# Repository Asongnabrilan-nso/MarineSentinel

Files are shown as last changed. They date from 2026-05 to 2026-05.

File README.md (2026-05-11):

# 🌊 MarineSentinel

MarineSentinel Floating on Ocean

AI-powered marine debris detection and water quality monitoring device. MarineSentinel floats on water bodies (oceans, seas, rivers) and continuously:

- **Detects plastic debris** (plastic bags, plastic bottles) via an Edge Impulse image-classification model running on the MPU.
- **Monitors water quality** (pH, turbidity, water temperature, TDS) via the MCU's sensor interface.
- **Streams all data** to a local in-device WebUI (real-time) and a remote Firebase dashboard (global access).
- **Shows live camera feed** in the local WebUI and uploads periodic snapshots to the remote Firebase dashboard.

---

## Table of Contents

1. [System Architecture](#system-architecture)
2. [Hardware Requirements](#hardware-requirements)
3. [Wiring Diagram](#wiring-diagram)
4. [Software Setup](#software-setup)
   - [A — UNO Q MCU Sketch (App Lab)](#a--uno-q-mcu-sketch-app-lab)
   - [B — UNO Q MPU Python App (App Lab)](#b--uno-q-mpu-python-app-app-lab)
   - [C — Firebase Remote Dashboard](#c--firebase-remote-dashboard)
5. [Edge Impulse AI Model](#edge-impulse-ai-model)
6. [Configuration & Thresholds](#configuration--thresholds)
7. [Project Structure](#project-structure)
8. [Troubleshooting](#troubleshooting)

---

## System Architecture

```
┌────────────────────────────────────────────────────────────────────┐
│                      Arduino UNO Q                                 │
│                                                                    │
│  ┌──────────────────────────────────┐  ┌───────────────────────┐  │
│  │  MPU  (Linux / Python)           │  │  MCU  (STM32 / C++)   │  │
│  │                                  │  │                       │  │
│  │  python/main.py                  │  │  sketch/sketch.ino    │  │
│  │  ├─ VideoObjectDetection brick   │  │  ├─ pH sensor (A0)    │  │
│  │  │   (Edge Impulse model)        │  │  ├─ Turbidity (A1)    │  │
│  │  ├─ WebUI brick  (local UI)      │  │  ├─ DS18B20  (D12)    │  │
│  │  ├─ Firebase Admin SDK           │  │  ├─ TDS sensor (A2)   │  │
│  │  ├─ Camera socket (port 4912)    │  │  └─ GPS (Serial2)     │  │
│  │  └─ Bridge.call("get_sensors")◄──┼──┼──Bridge.provide()     │  │
│  └──────────────────────────────────┘  └───────────────────────┘  │
└────────────────────────────────────────────────────────────────────┘

 ┌──────────────────────┐        ┌──────────────────────────────┐
 │  AI Runner  (port    │        │  Local WebUI  (port 7000)    │
 │  4912 Socket.IO)     │◄──────►│  Browser connects to both    │
 │  JPEG camera frames  │        │  port 7000 (data) and        │
 └──────────────────────┘        │  port 4912 (live camera)     │
                                 └──────────────────────────────┘

Local WebUI ──► browser on same network  http://<device-ip>:7000
Firebase    ──► global dashboard         https://your-project.web.app
```

### Data Flow

1. **AI Detection**: Camera → `VideoObjectDetection` brick → `process_detections()` → WebUI + Firebase
2. **Water Sensors**: MCU reads A0/A1/A2/D12 → Bridge `get_sensors` → Python → WebUI + Firebase
3. **GPS**: GPS module → MCU Serial2 → included in sensor JSON → Python parses NMEA → lat/lon in alerts
4. **Live Camera (local)**: Browser connects directly to AI runner Socket.IO on port 4912 — receives JPEG frames in real time
5. **Camera Snapshots (remote)**: Python subscribes to AI runner Socket.IO, compresses latest frame, uploads to Firebase every 30 s

---

## Hardware Requirements

| Component | Qty | Notes |
|---|---|---|
| Arduino UNO Q | 1 | MPU (Linux) + MCU (STM32) in one board |
| Camera module | 1 | Compatible with UNO Q App Lab camera brick |
| GPS module (UART) | 1 | e.g. Neo-6M / Neo-8M — 9600 baud UART output |
| pH sensor + circuit | 1 | Analog voltage output 0–5 V |
| Turbidity sensor | 1 | Analog voltage output |
| DS18B20 waterproof | 1 | 1-Wire, requires 4.7 kΩ pull-up resistor |
| TDS sensor *(optional)* | 1 | Analog voltage output |
| 4.7 kΩ resistor | 1 | Pull-up for DS18B20 data line |
| Waterproof float/enclosure | 1 | Housing for ocean/river deployment |

> **Note:** The Arduino Nano 33 BLE Sense environmental node has been suspended from this build.
> All sensing is handled directly by the UNO Q STM32 MCU block.

---

## Wiring Diagram

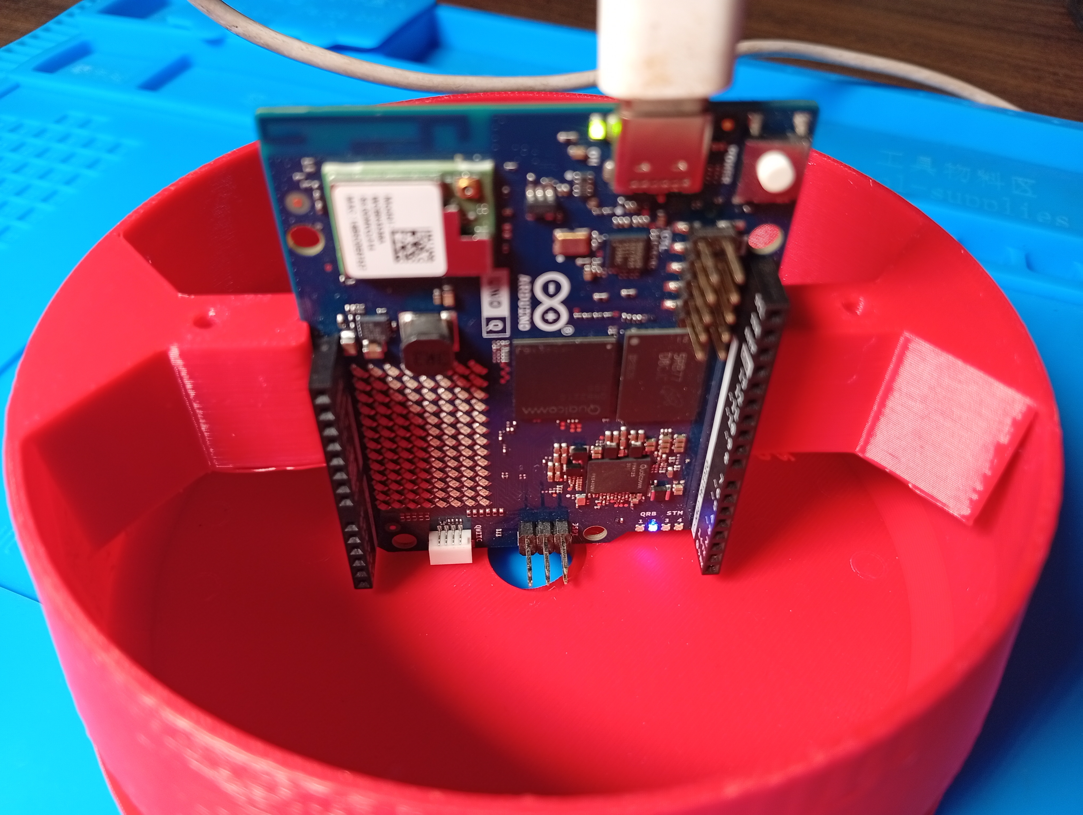
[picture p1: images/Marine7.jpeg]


### UNO Q STM32 MCU Pins

```
Sensor                   UNO Q pin
─────────────────────────────────────────────────────────
pH sensor AOUT      ──►  A0
Turbidity AOUT      ──►  A1
TDS sensor AOUT     ──►  A2          (optional)
DS18B20 data        ──►  D12  (4.7 kΩ pull-up to 5 V mandatory)
GPS module TX       ──►  Serial2 RX  (check UNO Q pinout for Serial2 pin)
GPS module VCC      ──►  3.3 V or 5 V (check GPS module datasheet)
GPS module GND      ──►  GND
```

---

## Software Setup

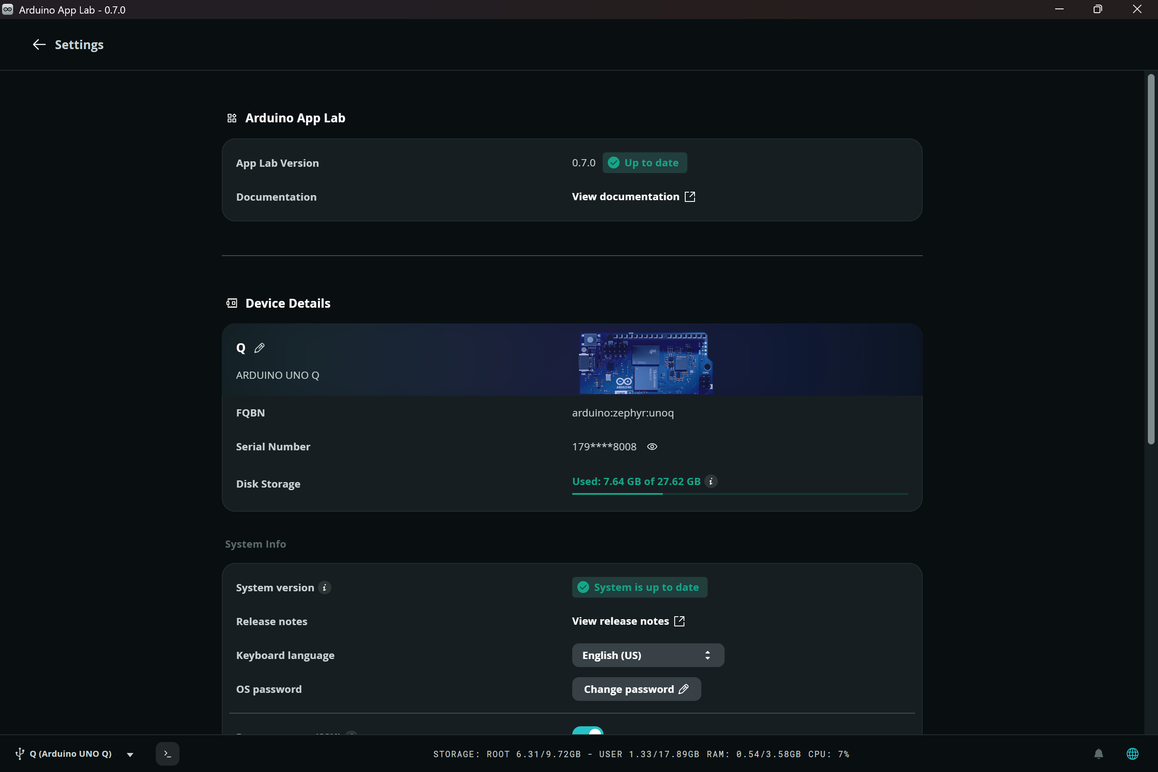
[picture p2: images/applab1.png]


### A — UNO Q MCU Sketch (App Lab)

The MCU sketch (`sketch/sketch.ino`) is managed by Arduino App Lab and runs on the STM32 block.

**Libraries** — App Lab installs these automatically from `sketch/sketch.yaml`:

| Library | Purpose |
|---|---|
| `Arduino_RouterBridge` | MCU ↔ MPU bridge communication |
| `OneWire` v2.3.8 | 1-Wire bus for DS18B20 |
| `DallasTemperature` v4.0.6 | DS18B20 water temperature reads |

**Boot LED sequence** — watch the UNO Q built-in LED after power-on:

| Pattern | Stage |
|---|---|
| 3 × fast blinks | Code started |
| 5 × fast blinks | Bridge handshake with MPU complete |
| 1 × long blink | All setup done — sensor loop running |
| 1 × short blink every 5 s | Sensor cache updated successfully |

---

### B — UNO Q MPU Python App (App Lab)

The Python app (`python/main.py`) runs on the Linux MPU block of the UNO Q.

**App bricks** (configured in `app.yaml`):

| Brick | Purpose |
|---|---|
| `arduino:video_object_detection` | Runs Edge Impulse model; streams camera to port 4912 |
| `arduino:web_ui` | Serves local WebUI from `assets/` directory on port 7000 |

**Firebase Admin SDK credential**

1. Open [Firebase Console](https://console.firebase.google.com) → your project.
2. Go to **Project Settings → Service Accounts → Generate new private key**.
3. Download the JSON file and copy it to:
   ```
   python/config/serviceAccountKey.json
   ```
4. Update `DATABASE_URL` at the top of `python/main.py`:
   ```python
   DATABASE_URL = "https://YOUR_PROJECT_ID-default-rtdb.firebaseio.com"
   ```

Python dependencies are auto-installed on first run and listed in `python/requirements.txt`:
```
pynmea2        — parses NMEA GPS sentences
firebase-admin — Firebase Realtime Database Admin SDK
```

The following packages are pre-installed in the App Lab base image and do **not** need to be listed in `requirements.txt`:
- `python-socketio` — receives camera frames from the AI runner
- `Pillow` — compresses frames before uploading to Firebase

**Local WebUI** is accessible at `http://<device-ip>:7000` once running. It displays:

- Live camera feed (JPEG frames streamed directly from the AI runner on port 4912)
- AI detection result: class label, confidence %, GPS coordinates
- Debris alert banner with geo-location (`lat°, lon°`) when plastic is detected
- Water quality tiles: pH, turbidity, water °C, TDS ppm
- Scrollable recent-alerts list with GPS stamp on debris events

---

### C — Firebase Remote Dashboard

The Firebase dashboard (`dashboard/public/`) enables worldwide remote monitoring.

**Step 1 — Create a Firebase project**

1. Go to [Firebase Console](https://console.firebase.google.com) → **Add project**.
2. Enable **Realtime Database** (create in test mode initially).
3. Enable **Hosting**.

**Step 2 — Configure the dashboard**

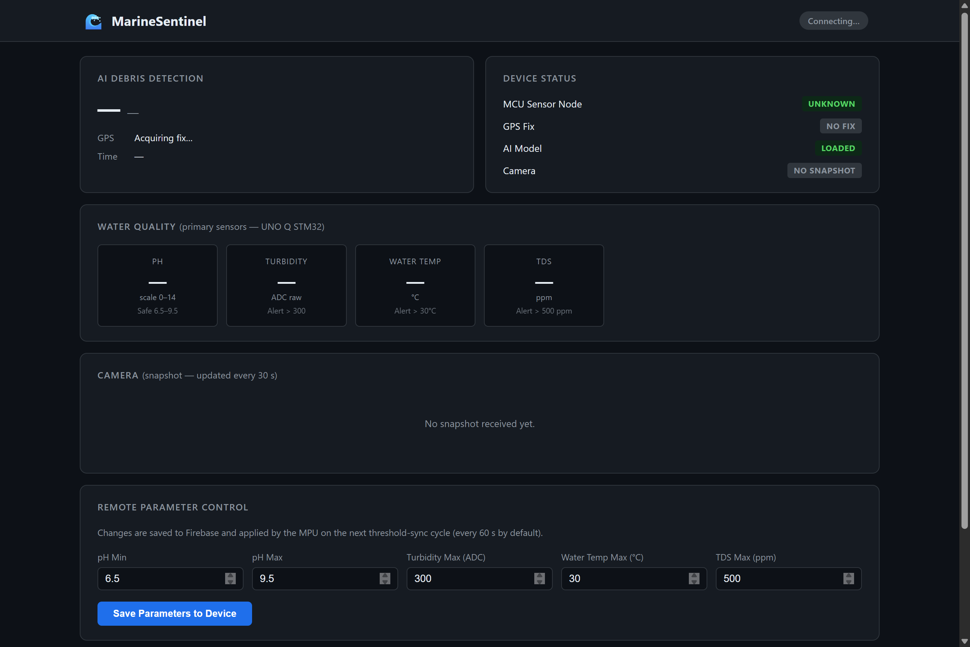
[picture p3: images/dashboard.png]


Open `dashboard/public/app.js` and replace the `firebaseConfig` block with your real project config
(find it at **Firebase Console → Project Settings → Your apps → SDK setup → Config**):

```javascript
const firebaseConfig = {
  apiKey:            'YOUR_API_KEY',
  authDomain:        'YOUR_PROJECT_ID.firebaseapp.com',
  databaseURL:       'https://YOUR_PROJECT_ID-default-rtdb.firebaseio.com',
  projectId:         'YOUR_PROJECT_ID',
  storageBucket:     'YOUR_PROJECT_ID.appspot.com',
  messagingSenderId: 'YOUR_SENDER_ID',
  appId:             'YOUR_APP_ID',
};
```

**Step 3 — Deploy to Firebase Hosting**

```bash
# Install Firebase CLI (once, requires Node.js)
npm install -g firebase-tools

# Authenticate
firebase login

# Deploy from the dashboard directory
cd dashboard
firebase deploy
```

Firebase prints a Hosting URL such as `https://your-project.web.app`. Open it anywhere in the world.

**Step 4 — Apply security rules**

```bash
cd dashboard
firebase database:rules:set database.rules.json
```

Current rules allow:
- **Public read** of `/device/*` and `/config/thresholds` — anyone with the URL can view live data.
- **Authenticated write** only — only signed-in users can change thresholds or write data.

**Dashboard features**:

- Live online/offline status + last-seen timestamp
- AI detection card with class label, confidence, GPS fix
- Water quality sensor tiles (colour-coded alert/ok)
- **Camera snapshot** — latest compressed JPEG from the device, refreshed every 30 s
- Remote threshold control — save new limits to Firebase; MPU pulls them every 60 s
- Recent alerts log (last 10 events)

---

## Edge Impulse AI Model

The model is configured in `app.yaml`:

```yaml
bricks:
  - arduino:video_object_detection:
      model: ei-model-949141-1
```

### Detection classes

| Class | Meaning |
|---|---|
| `plastic_bag` | Plastic bag visible in camera frame |
| `plastic_bottle` | Plastic bottle visible in camera frame |
| `ocean` | Open water — no debris detected |

Any class that is not `ocean` and exceeds the confidence threshold triggers a **DEBRIS alert** with the current GPS location.

### Confidence threshold

Default: **70 %** (`CONFIDENCE_THRESHOLD = 0.70` in `python/main.py`).
Adjustable at runtime via the confidence slider in the local WebUI.

---

## Configuration & Thresholds

Thresholds are defined in `python/main.py` and can be updated remotely from the Firebase dashboard.
The MPU pulls updates from `/config/thresholds` every 60 seconds (no restart required).

| Key | Default | Alert trigger |
|---|---|---|
| `ph_min` | 6.5 | pH drops below — acidic contamination |
| `ph_max` | 9.5 | pH rises above — alkaline contamination |
| `turbidity_max` | 300 ADC | Turbidity raw ADC exceeds value |
| `wtemp_max` | 30.0 °C | Water temperature above threshold |
| `tds_max` | 500 ppm | Total dissolved solids above threshold |

---

## Project Structure

```
marinesentinel_code/
│
├── app.yaml                        # App Lab project (bricks, ports, metadata)
│
├── python/                         # MPU — Linux side of Arduino UNO Q
│   ├── main.py                     # Main controller: AI, Bridge polling,
│   │                               # WebUI events, Firebase sync, camera socket
│   ├── requirements.txt            # Python package list
│   └── config/
│       └── serviceAccountKey.json  # Firebase Admin credential (keep private)
│
├── sketch/                         # MCU — STM32 side of Arduino UNO Q
│   ├── sketch.ino                  # Sensor reads + Bridge (pH, turbidity,
│   │                               # DS18B20, TDS, GPS)
│   └── sketch.yaml                 # Board profile + library dependencies
│
├── assets/                         # Local WebUI (served by the WebUI brick)
│   ├── index.html                  # Dashboard layout
│   ├── app.js                      # Socket.io client: sensors, detections,
│   │                               # camera (direct link to port 4912),
│   │                               # geo-located debris alerts
│   ├── style.css                   # Dark-theme responsive styles
│   └── libs/
│       └── socket.io.min.js        # Socket.IO v4 client library
│
├── nano33ble/
│   └── nano33ble.ino               # SUSPENDED — Nano 33 BLE Sense sketch
│                                   # (not used in current build)
│
├── dashboard/                      # Firebase-hosted global dashboard
│   ├── firebase.json               # Hosting + Database config
│   ├── database.rules.json         # Realtime Database security rules
│   └── public/
│       ├── index.html              # Remote monitoring layout
│       ├── app.js                  # Firebase DB listeners, camera snapshot,
│       │                           # threshold control
│       └── style.css               # Dashboard styles
│
└── README.md                       # Setup and deployment guide (this file)
```

---

## Troubleshooting

### Camera feed not showing in local WebUI

The browser opens two Socket.IO connections: one to port 7000 (data) and one to port 4912 (camera frames). Port 4912 is served by the AI runner container.

- Ensure the App Lab project is running (both bricks must be healthy).
- Check browser console for WebSocket errors to port 4912.
- The AI runner must complete its healthcheck (port 5050) before the camera socket is active.

### Camera snapshot not appearing on remote dashboard

- The Python app connects to the AI runner Socket.IO on port 4912. Check MPU logs for `[Camera]` lines.
- Snapshots upload to Firebase at `/device/camera/snapshot` every 30 s (only when a frame is available).
- If `HOST_IP` env var is missing, Python falls back to the Docker service name `ei-video-obj-detection-runner`.

### GPS — always `fix: false`

- GPS needs a clear sky to acquire a fix; avoid indoor testing without a GPS simulator.
- Confirm the GPS module TX wire goes to the **Serial2 RX** pin on the UNO Q.
- Only `$GNGGA` and `$GPGGA` NMEA sentences are accepted; other sentence types are discarded.

### Firebase — data not appearing on remote dashboard

- Confirm `python/config/serviceAccountKey.json` exists and belongs to the correct project.
- Match `DATABASE_URL` in `python/main.py` exactly to your Realtime Database URL.
- Look for `[Firebase] Write ... failed:` messages in the MPU Python console.

### pH reading stuck at 7.0

- 2.5 V on A0 maps to pH 7.0. A floating pin reads mid-rail. Confirm the pH probe is connected to A0 with power and GND.

### DS18B20 returns −127 °C

- No 1-Wire device detected. Check the **4.7 kΩ pull-up** between D12 and 5 V, and the sensor's DATA/VCC/GND connections.

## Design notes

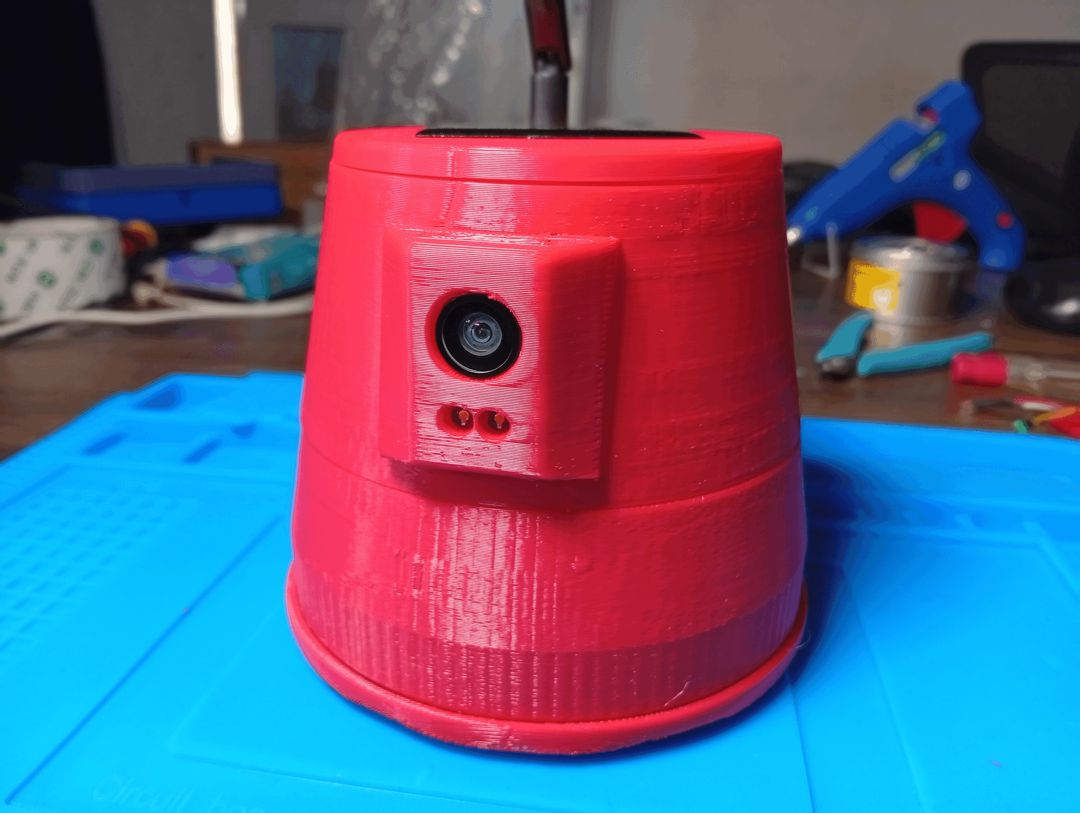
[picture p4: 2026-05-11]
images/Marine6.gif

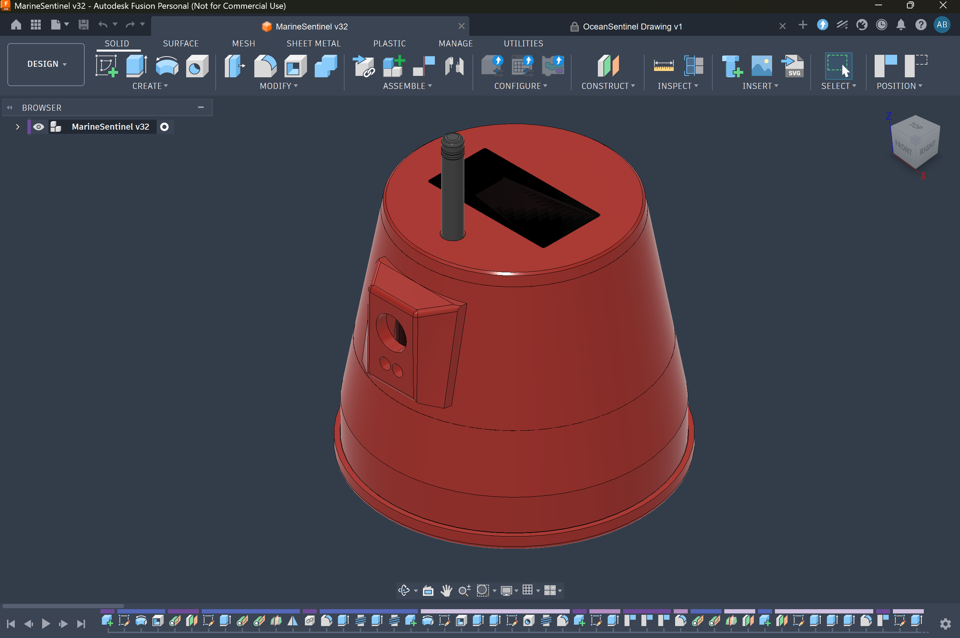
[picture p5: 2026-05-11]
images/Screenshot 2026-05-09 222934.png

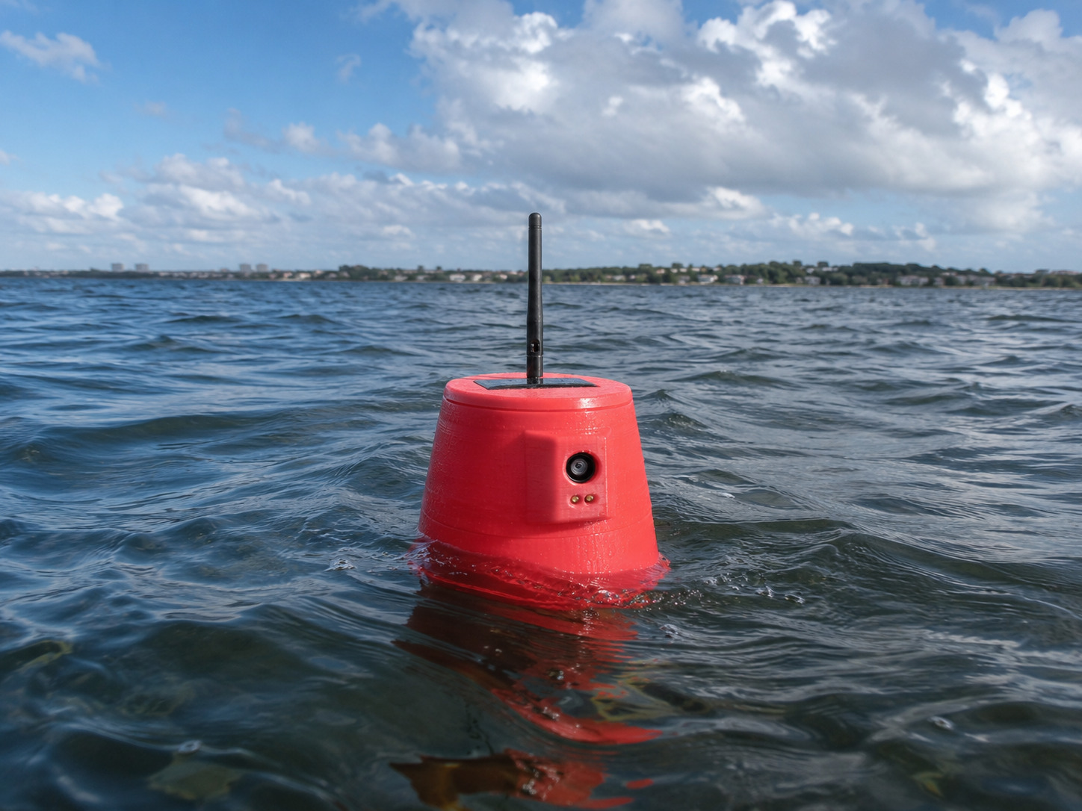
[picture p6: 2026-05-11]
images/Marine3.jpg

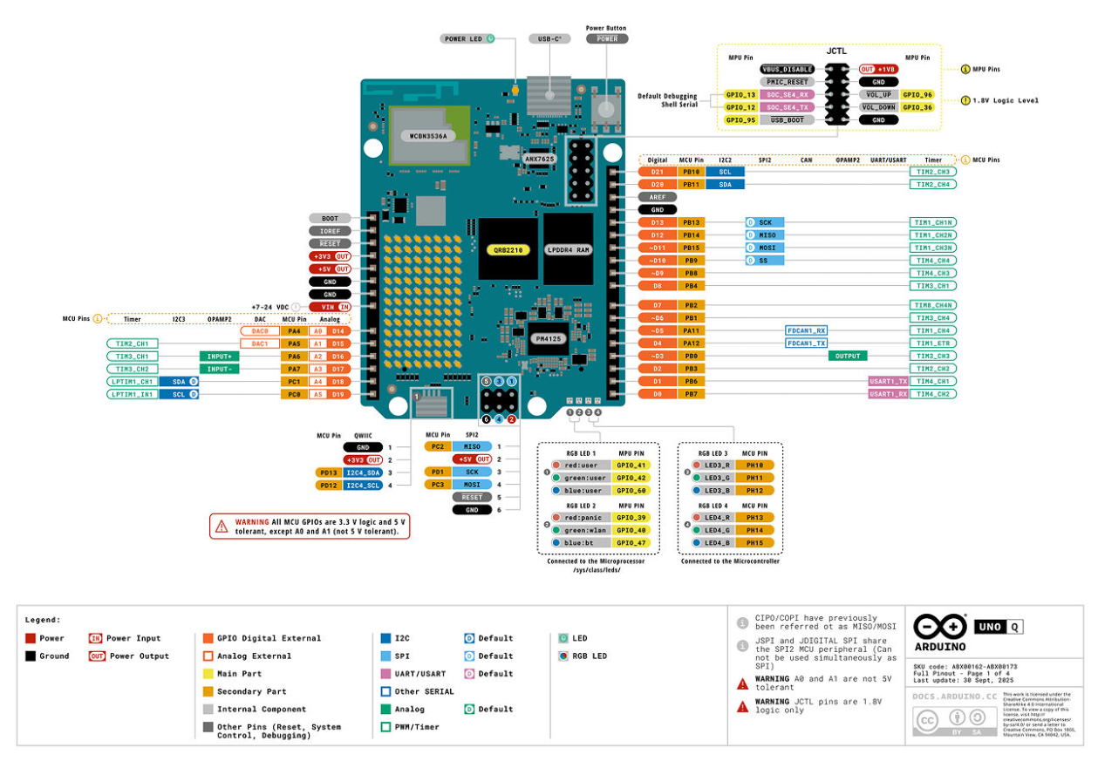
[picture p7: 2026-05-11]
images/Screenshot 2026-04-27 094548.png

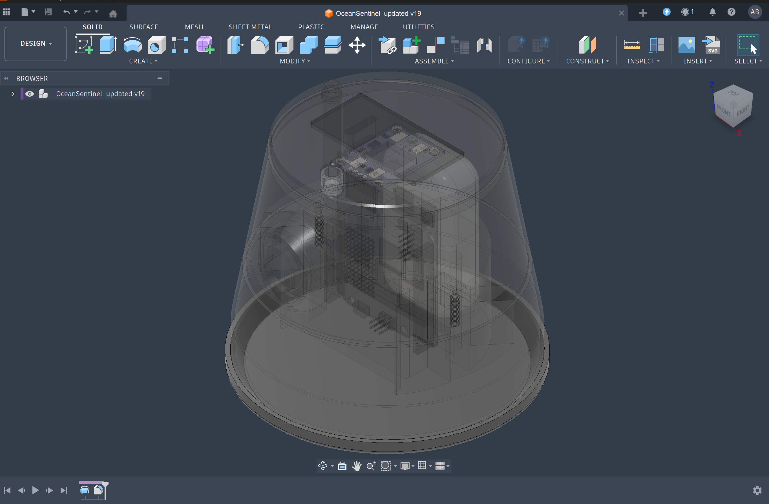
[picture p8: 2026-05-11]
images/Screenshot 2026-04-25 153714.png

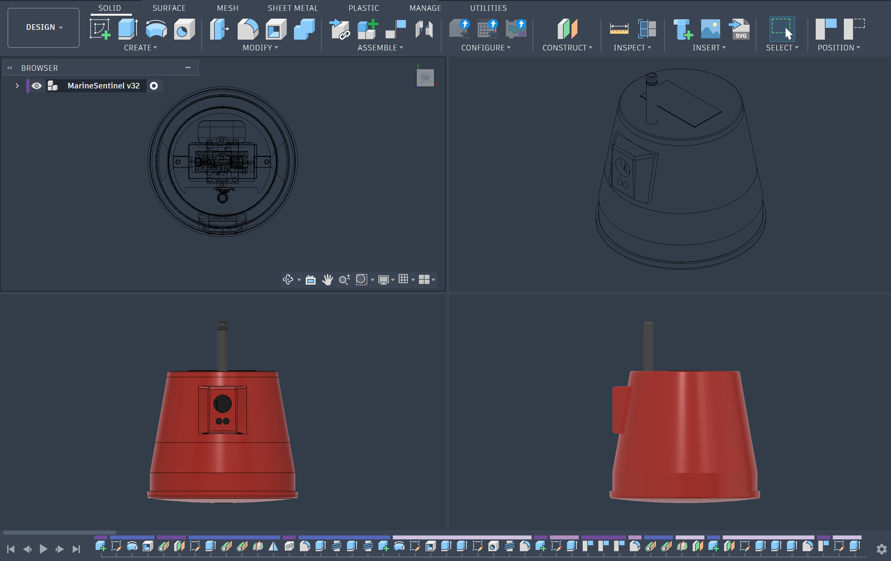
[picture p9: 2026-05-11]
images/Screenshot 2026-05-09 222451.png

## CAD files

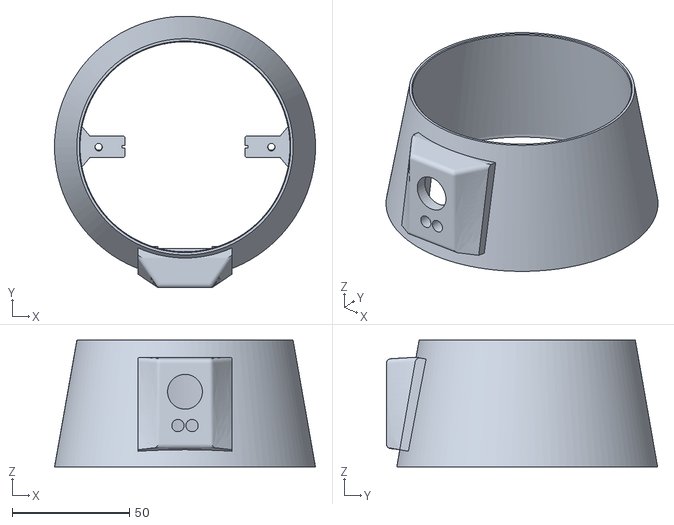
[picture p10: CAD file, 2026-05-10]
mechanical/3D Printing/Buoy Mid Section.stl
111.2 x 115.6 x 54.0

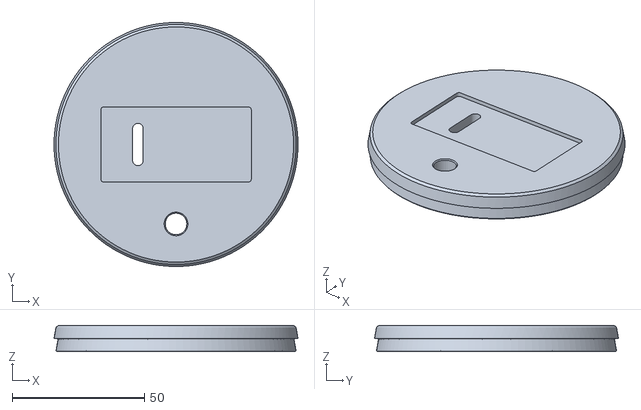
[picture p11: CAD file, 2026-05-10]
mechanical/3D Printing/Buoy Top.stl
92.1 x 92.1 x 10.0

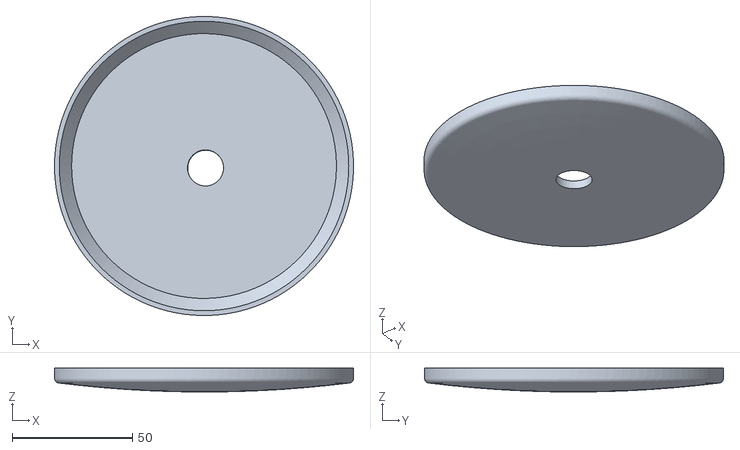
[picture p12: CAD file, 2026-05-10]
mechanical/3D Printing/Floating Base.stl
124.4 x 124.4 x 9.92

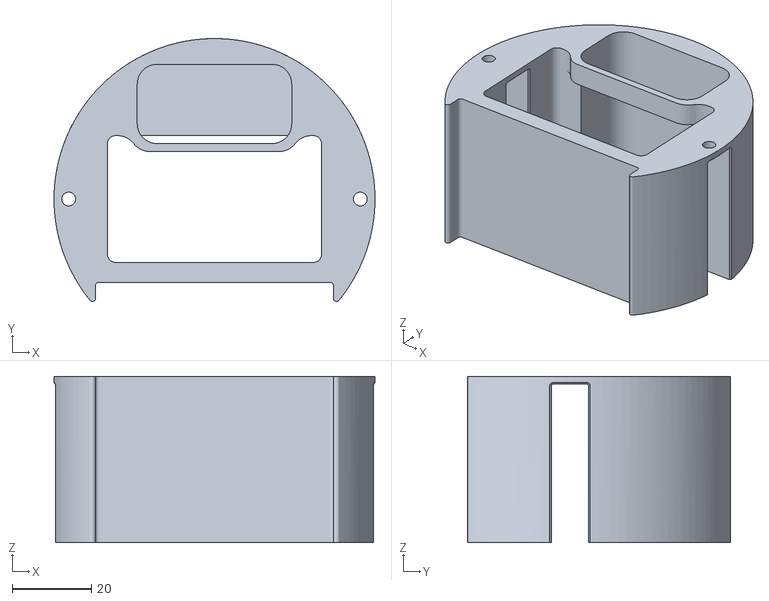
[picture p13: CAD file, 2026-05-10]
mechanical/3D Printing/Body1.stl
81.0 x 66.3 x 42.0

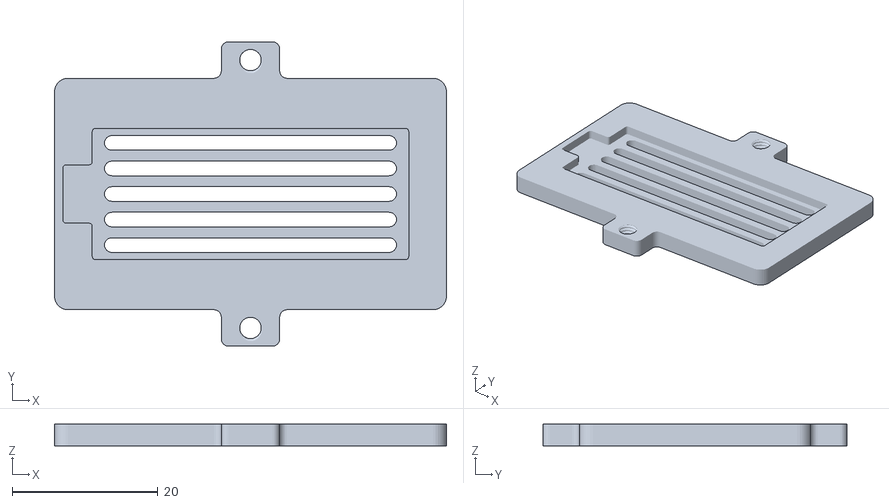
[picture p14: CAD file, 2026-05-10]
mechanical/3D Printing/Nano BLE Slot.stl
53.7 x 41.7 x 3.00

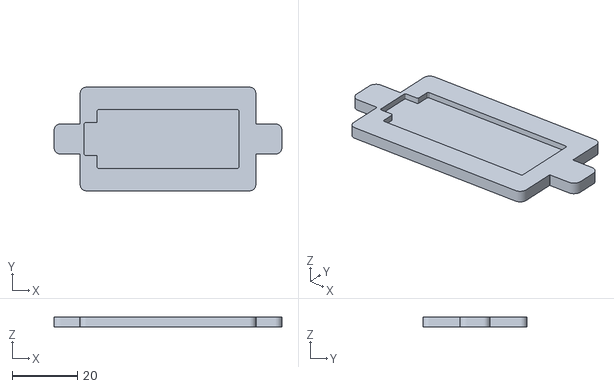
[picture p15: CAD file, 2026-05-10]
mechanical/3D Printing/NANO BLE Case.stl
69.7 x 31.7 x 3.00

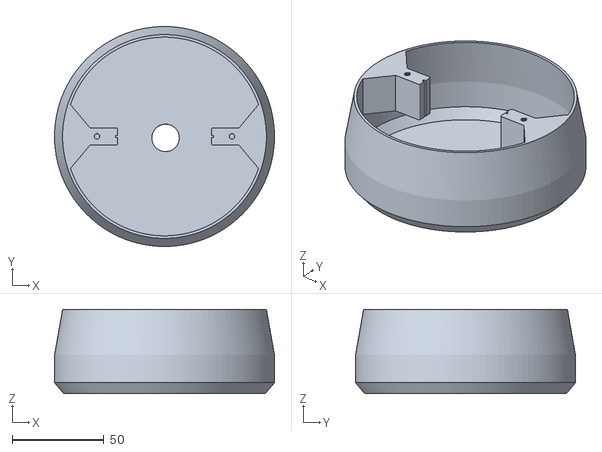
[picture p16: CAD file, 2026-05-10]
mechanical/3D Printing/Buoy Buttom.stl
120.0 x 120.0 x 46.0

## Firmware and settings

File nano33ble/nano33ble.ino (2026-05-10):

// =============================================================================
// MarineSentinel — Nano 33 BLE Sense Peripheral Node
// =============================================================================
//
// Upload this sketch to the Arduino Nano 33 BLE Sense using Arduino IDE 2.3.
// This file is STANDALONE — it is NOT part of the Arduino App Lab project.
//
// Role:
//   Provides real-time environmental + stability data to the UNO Q MCU.
//   When the UNO Q sends "GET_SENSORS\n" over UART, this sketch reads all
//   onboard sensors and replies with a single CSV line that the UNO Q parses.
//
// Wiring  (UNO Q STM32 side  ↔  Nano 33 BLE Sense):
//   UNO Q D1 (Serial1 TX)  ───►  Nano D0 (Serial1 RX)
//   UNO Q D0 (Serial1 RX)  ◄───  Nano D1 (Serial1 TX)
//   UNO Q GND              ────   Nano GND   ← REQUIRED common ground
//   UNO Q 3.3 V (optional) ────   Nano 3.3 V (or power Nano via its own USB)
//
// Response format (one line, newline-terminated, no spaces):
//   ATEMP:23.5,HUM:65.2,PRESS:1013.5,AX:0.01,AY:-0.02,AZ:0.99,GX:0.5,GY:-0.3,GZ:0.1
//
// Required Arduino libraries — install via Arduino IDE → Library Manager:
//   • Arduino_HTS221   v1.0+   (air temperature + relative humidity)
//   • Arduino_LPS22HB  v1.0+   (barometric pressure)
//   • Arduino_LSM9DS1  v1.1+   (accelerometer + gyroscope)
//
// Board package (Boards Manager):
//   "Arduino Mbed OS Nano Boards"
//   Board: Arduino Nano 33 BLE  (or Arduino Nano 33 BLE Sense)
//
// NOTE — Nano 33 BLE Sense Rev2 users:
//   Rev2 ships with different ICs (HS3003, BMI270, BMM150).
//   Replace the three #include lines and sensor init/read calls with the
//   corresponding Rev2 libraries (Arduino_HS300x, Arduino_BMI270_BMM150).
//   The response format stays identical.
// =============================================================================

#include <Arduino_HTS221.h>   // HTS221  — air temperature + humidity
#include <Arduino_LPS22HB.h>  // LPS22HB — barometric pressure
#include <Arduino_LSM9DS1.h>  // LSM9DS1 — 6-DOF IMU (accel + gyro)

// ── Configuration ─────────────────────────────────────────────────────────────
#define UART_BAUD  9600   // Must match UART_NANO_BAUD in the UNO Q sketch

// ── Sensor availability flags ──────────────────────────────────────────────────
static bool hts_ok = false;   // HTS221  initialised successfully
static bool lps_ok = false;   // LPS22HB initialised successfully
static bool imu_ok = false;   // LSM9DS1 initialised successfully

// ── UART receive accumulation buffer ──────────────────────────────────────────
static String rxBuf;   // command characters accumulate here until '\n'

// ── Latest sensor readings (updated on each GET_SENSORS request) ──────────────
static float s_atemp = 0.0f;               // air temperature   °C
static float s_hum   = 0.0f;               // relative humidity  %
static float s_press = 0.0f;               // pressure          hPa
static float s_ax = 0.0f, s_ay = 0.0f, s_az = 1.0f;  // acceleration g
static float s_gx = 0.0f, s_gy = 0.0f, s_gz = 0.0f;  // rotation     °/s

// =============================================================================
// LED helper
// The Nano 33 BLE Sense LED is active-LOW: LOW → ON, HIGH → OFF.
// =============================================================================
void blinkLED(int count, int ms) {
  for (int i = 0; i < count; i++) {
    digitalWrite(LED_BUILTIN, LOW);   // ON
    delay(ms);
    digitalWrite(LED_BUILTIN, HIGH);  // OFF
    delay(ms);
  }
}

// =============================================================================
// setup()
// =============================================================================
void setup() {
  pinMode(LED_BUILTIN, OUTPUT);
  digitalWrite(LED_BUILTIN, HIGH);  // LED off at boot

  // ── USB serial (debug only; device must work headless without USB) ──────────
  Serial.begin(115200);
  unsigned long t0 = millis();
  while (!Serial && millis() - t0 < 2000);  // wait ≤ 2 s for USB host
  Serial.println("[Nano] === MarineSentinel Nano 33 BLE Sense booting ===");

  // ── UART to UNO Q (pins D0=RX, D1=TX) ─────────────────────────────────────
  Serial1.begin(UART_BAUD);
  rxBuf.reserve(32);
  Serial.print("[Nano] Serial1 ready — "); Serial.print(UART_BAUD); Serial.println(" baud to UNO Q");

  // ── HTS221 — air temperature + humidity ────────────────────────────────────
  if (HTS.begin()) {
    hts_ok = true;
    Serial.println("[Nano] HTS221  OK (air temp + humidity)");
  } else {
    Serial.println("[Nano] WARN: HTS221 not found — check board revision");
  }

  // ── LPS22HB — barometric pressure ──────────────────────────────────────────
  if (BARO.begin()) {
    lps_ok = true;
    Serial.println("[Nano] LPS22HB OK (pressure)");
  } else {
    Serial.println("[Nano] WARN: LPS22HB not found");
  }

  // ── LSM9DS1 — 6-DOF IMU (accelerometer + gyroscope) ───────────────────────
  if (IMU.begin()) {
    imu_ok = true;
    Serial.print("[Nano] LSM9DS1 OK (IMU @ ");
    Serial.print(IMU.accelerationSampleRate(), 0);
    Serial.println(" Hz accel)");
  } else {
    Serial.println("[Nano] WARN: LSM9DS1 not found");
  }

  // 5 blinks → fully initialised
  blinkLED(5, 80);
  Serial.println("[Nano] Ready — waiting for GET_SENSORS commands.");
}

// =============================================================================
// readSensors()
// Refresh all cached sensor values. Called only when GET_SENSORS is received
// so that the UART reply contains fresh readings.
// =============================================================================
void readSensors() {
  if (hts_ok) {
    s_atemp = HTS.readTemperature();  // °C
    s_hum   = HTS.readHumidity();     // %
  }

  if (lps_ok) {
    // readPressure() returns kPa — multiply by 10 to convert to hPa.
    // Standard atmosphere: 101.325 kPa = 1013.25 hPa ✓
    s_press = BARO.readPressure() * 10.0f;
  }

  if (imu_ok) {
    // Only read when new sample is available to avoid stale data.
    if (IMU.accelerationAvailable()) {
      IMU.readAcceleration(s_ax, s_ay, s_az);  // g
    }
    if (IMU.gyroscopeAvailable()) {
      IMU.readGyroscope(s_gx, s_gy, s_gz);  // °/s
    }
  }
}

// =============================================================================
// sendSensorData()
// Build and transmit the CSV reply to the UNO Q.
// Key names must exactly match what the UNO Q's parseField() looks for.
// =============================================================================
void sendSensorData() {
  readSensors();

  char buf[128];
  snprintf(buf, sizeof(buf),
    "ATEMP:%.1f,HUM:%.1f,PRESS:%.1f,"
    "AX:%.2f,AY:%.2f,AZ:%.2f,"
    "GX:%.1f,GY:%.1f,GZ:%.1f",
    s_atemp, s_hum, s_press,
    s_ax,    s_ay,  s_az,
    s_gx,    s_gy,  s_gz
  );

  // '\n' signals end-of-line to the UNO Q's pollNanoResponse() reader.
  Serial1.println(buf);
  Serial1.flush();

  Serial.print("[Nano] >> ");
  Serial.println(buf);

  blinkLED(1, 30);  // brief confirmation flash per successful reply
}

// =============================================================================
// loop()
// Non-blocking UART command receiver.
// Accumulates bytes until '\n', then dispatches if command == "GET_SENSORS".
// Never blocks so it remains responsive to back-to-back commands.
// =============================================================================
void loop() {
  while (Serial1.available()) {
    char c = (char)Serial1.read();

    if (c == '\n' || c == '\r') {
      if (rxBuf.length() > 0) {
        rxBuf.trim();

        if (rxBuf.equalsIgnoreCase("GET_SENSORS")) {
          sendSensorData();
        } else {
          // Log unknown commands for debugging; do not hang or reset.
          Serial.print("[Nano] Unknown cmd: ");
          Serial.println(rxBuf);
        }

        rxBuf = "";
      }
      // Ignore lone \r or blank lines.
    } else if (rxBuf.length() < 30) {
      // 30-char guard prevents unbounded growth if line noise prevents '\n'.
      rxBuf += c;
    }
  }
}

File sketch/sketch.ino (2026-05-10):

// MarineSentinel — MCU Sensor Interface
// Runs on: Arduino UNO Q — STM32 MCU block
// Environment: Arduino App Lab
//
// Serial port assignments
//   Serial   App Lab / USB console  115200 baud
//   Serial2  GPS module             9600 baud   board-specific pins
//
// Wiring (UNO Q STM32 side):
//   pH sensor    AOUT → A0
//   Turbidity    AOUT → A1
//   DS18B20 data      → D12  (4.7 kΩ pull-up to 5 V is mandatory)
//   TDS sensor   AOUT → A2
//   GPS TX            → Serial1 RX pin  (check UNO Q pinout)
//   GPS module VCC    → 3.3 V or 5 V
//   All GNDs connected

#include <Arduino_RouterBridge.h>
#include <OneWire.h>
#include <DallasTemperature.h>

// ── Pin assignments ────────────────────────────────────────────────────────────
#define PH_PIN         A0
#define TURBIDITY_PIN  A1
#define DS18B20_PIN    12
#define TDS_PIN        A2

// ── Timing ────────────────────────────────────────────────────────────────────
#define SENSOR_UPDATE_MS  5000
#define GPS_BAUD          9600

OneWire           oneWire(DS18B20_PIN);
DallasTemperature waterTempSensor(&oneWire);

unsigned long lastUpdate = 0;
String        lastNmea   = "";
char          sensorCache[256] = "{}";

// ── LED helper ────────────────────────────────────────────────────────────────
void blinkLED(int times, int ms) {
  for (int i = 0; i < times; i++) {
    digitalWrite(LED_BUILTIN, HIGH); delay(ms);
    digitalWrite(LED_BUILTIN, LOW);  delay(ms);
  }
}

// ── Bridge callbacks ──────────────────────────────────────────────────────────
String getSensors() { return String(sensorCache); }

void set_alert(int severity) {
  if (severity > 0) blinkLED(severity, 200);
}

void ping(int dummy) { Serial.println("[MCU] PONG"); }

// ── Setup ─────────────────────────────────────────────────────────────────────
void setup() {
  pinMode(LED_BUILTIN, OUTPUT);

  // Stage 1 — 3 fast blinks: code started
  blinkLED(3, 80);

  Serial.begin(115200);
  delay(500);
  Serial.println("[MCU] === MarineSentinel booting ===");

  // Stage 2 — GPS serial
  Serial1.begin(GPS_BAUD);
  Serial.println("[MCU] Serial2 ready (GPS)");

  // Stage 3 — water sensors
  waterTempSensor.begin();
  Serial.println("[MCU] DS18B20 ready");

  // Stage 4 — Bridge
  // Bridge.begin() blocks until the MPU Python side is running.
  Serial.println("[MCU] Starting Bridge — waiting for MPU handshake...");
  Bridge.begin();
  Serial.println("[MCU] Bridge ready");

  // Stage 5 — 5 blinks: past Bridge.begin()
  blinkLED(5, 80);

  Bridge.provide("get_sensors", getSensors);
  Bridge.provide("set_alert",   set_alert);
  Bridge.provide("ping",        ping);

  // 1 long blink — all setup done
  blinkLED(1, 500);
  Serial.println("[MCU] Setup complete. Sensor loop running.");
}

// ── Main loop ─────────────────────────────────────────────────────────────────
void loop() {
  Bridge.update();

  // Buffer GPS NMEA sentences non-blocking
  while (Serial1.available()) {
    String line = Serial1.readStringUntil('\n');
    line.trim();
    if (line.startsWith("$GNGGA") || line.startsWith("$GPGGA")) {
      lastNmea = line;
    }
  }

  if (millis() - lastUpdate >= SENSOR_UPDATE_MS) {
    lastUpdate = millis();
    updateSensorCache();
  }
}

// ── Sensor cycle ──────────────────────────────────────────────────────────────
// Reads all local sensors (DS18B20 blocks ~750 ms at 12-bit) and
// updates the JSON cache that Bridge.provide returns to the MPU.
void updateSensorCache() {
  Serial.println("[MCU] ---- sensor cycle ----");

  // pH
  int   phRaw  = analogRead(PH_PIN);
  float phVolt = phRaw * (5.0f / 1023.0f);
  float ph = constrain(7.0f + ((2.5f - phVolt) / 0.18f), 0.0f, 14.0f);

  // Turbidity
  int turbRaw = analogRead(TURBIDITY_PIN);

  // Water temperature — requestTemperatures() blocks ~750 ms at 12-bit resolution
  waterTempSensor.requestTemperatures();
  float wTemp = waterTempSensor.getTempCByIndex(0);

  // TDS
  int   tdsRaw  = analogRead(TDS_PIN);
  float tdsVolt = tdsRaw * (5.0f / 1023.0f);
  float tds = (133.42f * tdsVolt * tdsVolt * tdsVolt
              - 255.86f * tdsVolt * tdsVolt
              + 857.39f * tdsVolt) * 0.5f;

  Serial.print("[MCU] pH:"); Serial.print(ph, 2);
  Serial.print("  turb:");   Serial.print(turbRaw);
  Serial.print("  wTemp:");  Serial.print(wTemp, 1);
  Serial.print("  tds:");    Serial.println(tds, 0);

  snprintf(sensorCache, sizeof(sensorCache),
    "{\"ph\":%.2f,\"turb\":%d,\"wtemp\":%.1f,\"tds\":%.0f,\"gps\":\"%s\"}",
    ph, turbRaw, wTemp, tds, lastNmea.c_str());

  Serial.println("[MCU] Cache updated.");
  blinkLED(1, 50);
}
